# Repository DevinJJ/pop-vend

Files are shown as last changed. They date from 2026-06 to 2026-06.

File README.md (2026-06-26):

# PopVend
PopVend is a 3D-printed mini vending machine that uses a Trigr.dev QR code to accept instant card payments.

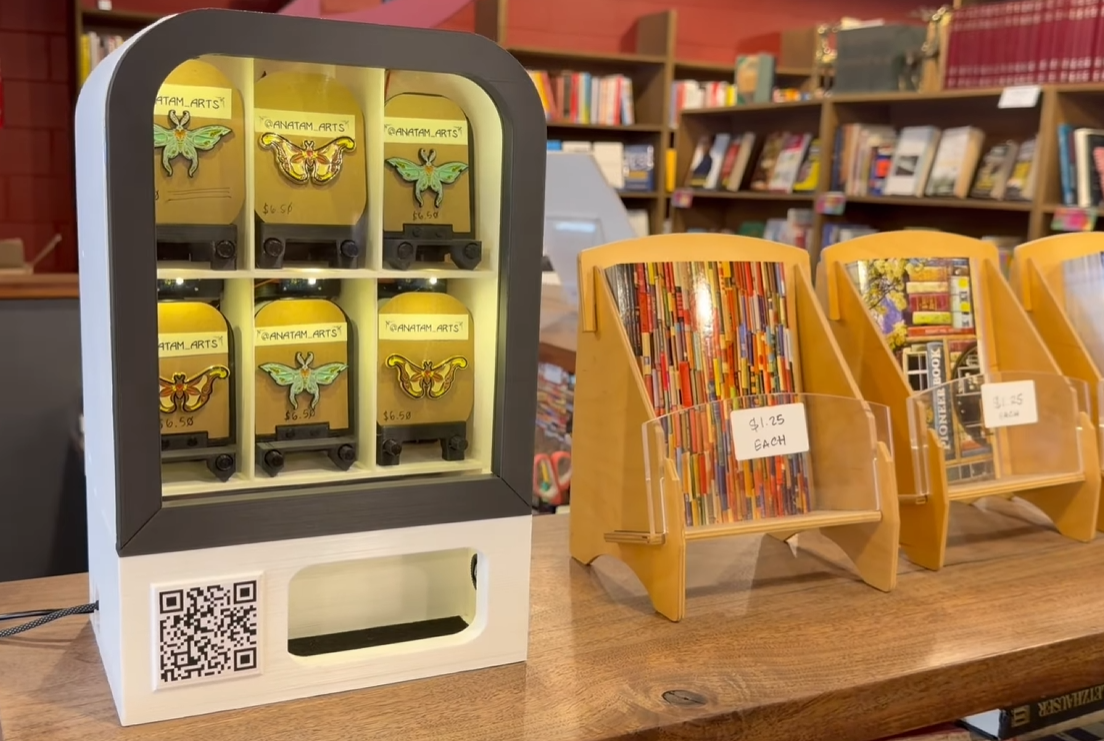
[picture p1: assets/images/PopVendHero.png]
popvend-hero


## Features

* 6 unique item slots that can fit things about the height and length of a credit card
* Fully electronic and automatic vending
* Small front screen with customizable scrolling idle text
* Customizable RGB LEDs above each product
* QR code payments using [Trigr.dev](https://trigr.dev) - Triggers vends instantly after online payments, and payment goes instantly to your own Stripe account  

To print the parts you will need access to a 3D printer that can print up to 250mm high and 142mmx215mm.

**The full build is designed for makers that have some knowledge of electronics, soldering skills and a basic understanding of the Arduino IDE.** As of right now, there are only unsoldered boards available on my [Ko-fi page](https://ko-fi.com/devmode). However, pre-soldered circuit boards and some helpful kits will be available soon that will make the build much much easier. 

## How To Build

Full build tutorial coming soon

## How to use Stripe and Trigr for QR code payments

Once your vending machine is all put together and working, it's time to get it set up to vend automatically with Stripe payments. Luckily, this is made very easy with [Trigr.dev](https://trigr.dev) . 

### Step 1: Make a Trigr account & connect your Stripe account

First, [create an a free account on Trigr](https://trigr.dev/auth/register). Once your account is set up, you will need to follow the instructions to verify your email. Once your email has been verified, you can onboard your Stripe account. To onboard your Stripe account, click the yellow start button at the top of your Trigr dashboard:

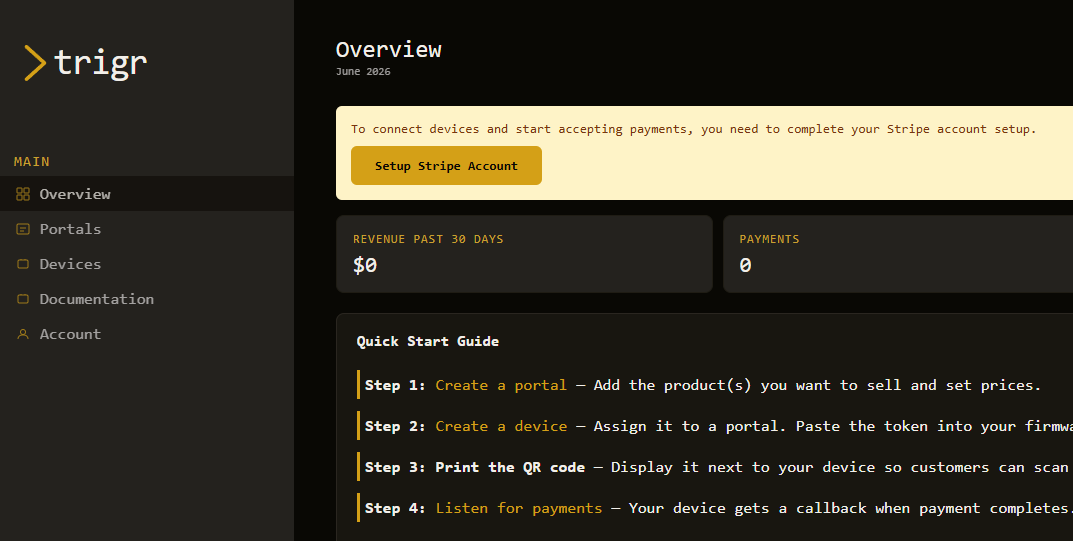
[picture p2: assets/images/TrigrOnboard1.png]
triger-onboarding-dashboard


This will launch the official Stripe onboarding process. If you already have Stripe account that you want to use, that's okay, use that information and it will make onboarding faster.

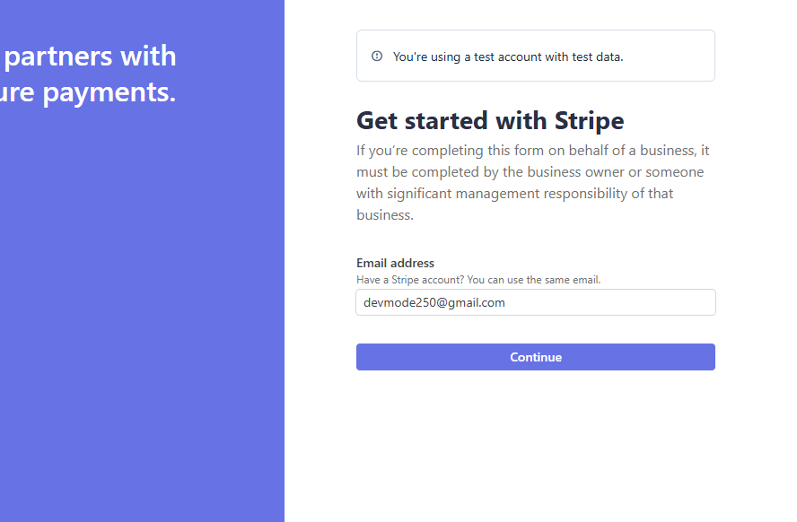
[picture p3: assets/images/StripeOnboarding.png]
stripe-onboarding-first-page


Sometimes it takes a few hours for your info to be processed and approved. You can check your Stripe connection status on your "Account" tab:

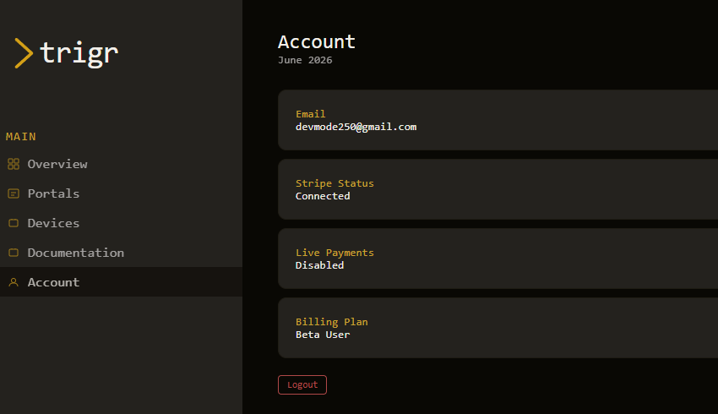
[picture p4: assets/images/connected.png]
trigr-account-tab


### Step 2: Create your Checkout Portal and get your Device token

Next, click on the "Portals" tab in your Trigr dashboard, and click "+ New Portal". This is where you will specify which products you are selling in your vending machine. 

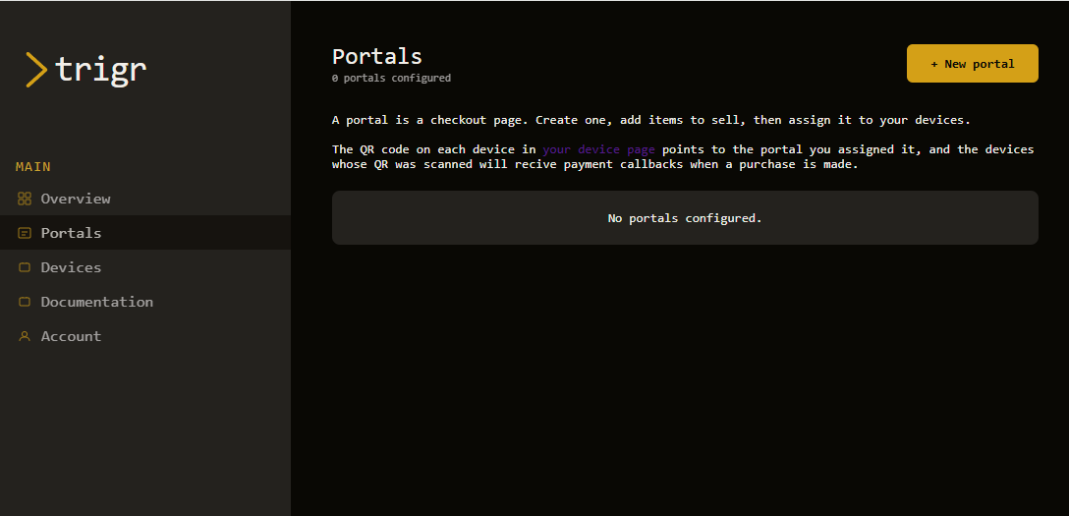
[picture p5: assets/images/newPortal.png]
trigr-portals-tab


Add a product for ALL 6 shelves in the machine, even if they are the same product.

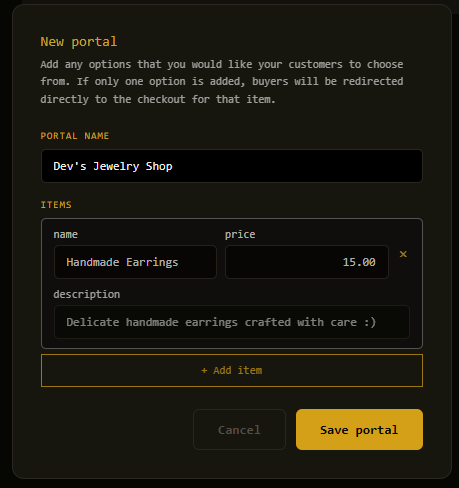
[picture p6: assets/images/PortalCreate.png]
trigr-portal-creation


Once your portal is made, go to the "Devices" tab to create your device. During device creation, use the "portal" dropdown to select the portal you just created.

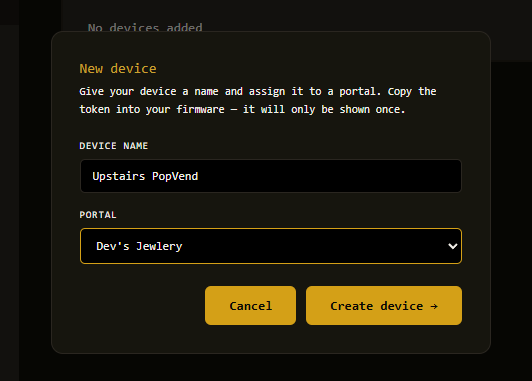
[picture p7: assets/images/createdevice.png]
trigr-device-creation


Once that is done, your Trigr portal is all set up to accept payments from your vending machine. However, keep this page open because you will need it one more time in the final step.

### Step 3: Copy your Trigr tokens into your firmware, and print your QR code

Just a few more things before you're ready to display your machine.

First, you will need to copy some of the tokens that are now available in your Trigr account into your Arduino firmware to flash onto your esp32. Directly at the top of the Arduino firmware provided in '/firmware' are a bunch of configurable parameters to customize your vending machine: 

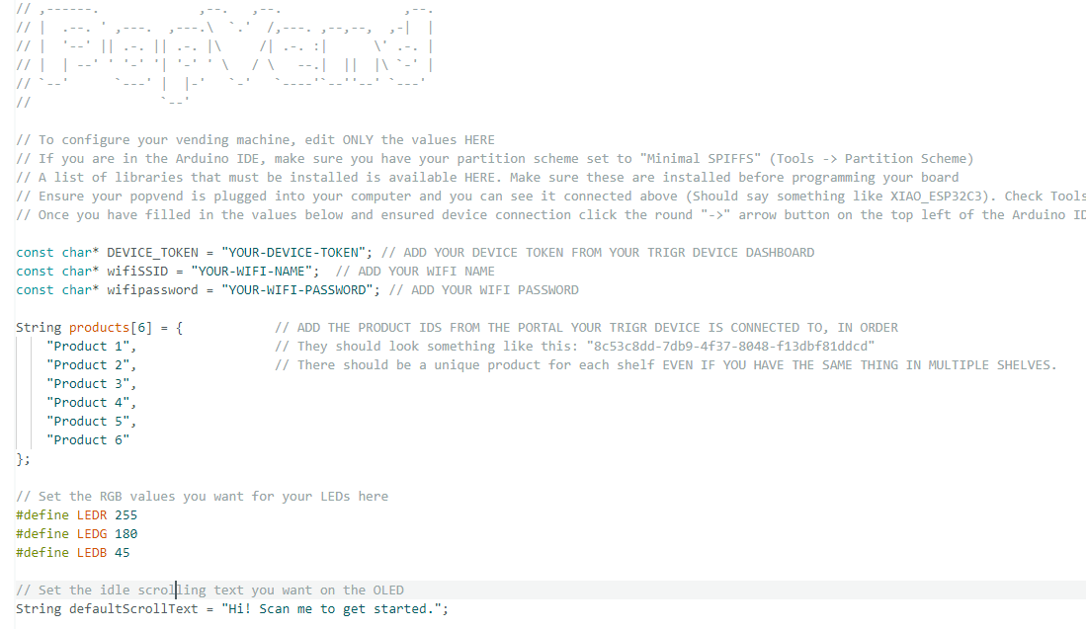
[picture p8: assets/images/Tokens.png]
arduino-ide-firmware-tokens


Here you can customize the LED colors and the scroll text, as well as set up your WiFi credentials and Trigr tokens.

To get your Trigr device token, go back to the "Devices" tab on your Trigr dashboard. Just click on the "Copy Device ID" button and paste it into the Arduino IDE:

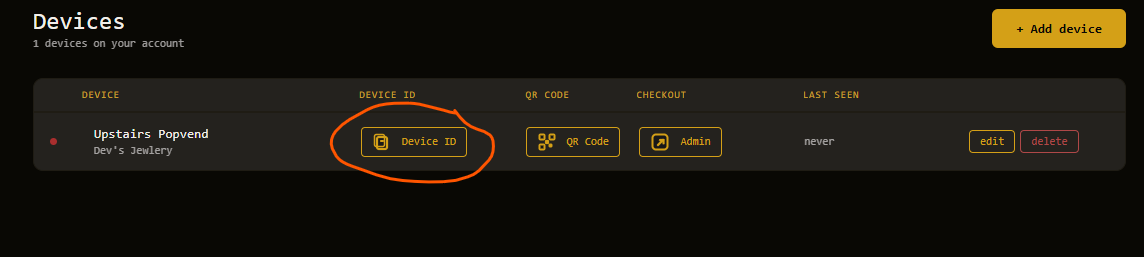
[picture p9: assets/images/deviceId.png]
trigr-copy-device-id


Next, **you will need to add a token for each SHELF in the vending machine (each token should be unique, even if you are selling the same thing on multiple shelves...** just make a separate product for each shelf). To do that, go back to the "Portals" tab and find the portal you set up with your products. There is a "Copy" button displayed next to each product in the portal. There should always be six of these when setting up a PopVend. Copy each one over to the firmware, replacing the text between the quotations marks on lines 19 through 24.

And that's it! Once you re-flash your board with that firmware, you should see the device come online on your Trigr portal. To test your machine, go back to the "Devices" tab and click the "Admin" button on your device. This will take you to a checkout page similar to what a customer will see when they scan your device QR code. Here, you can click on each product and simulate a payment going through by clicking "Trigger Payment Confirmed".

One last thing you'll want to do is go back to the "Devices" tab and click the "QR code" button. This will generate a QR code specifically for your device that you can download to print and mount on your vending machine.

---
*Created by [Devmode](https://www.devinjames.tech/). Need help with your build? Join the [Discord server](https://discord.gg/Y6D79bpH)!

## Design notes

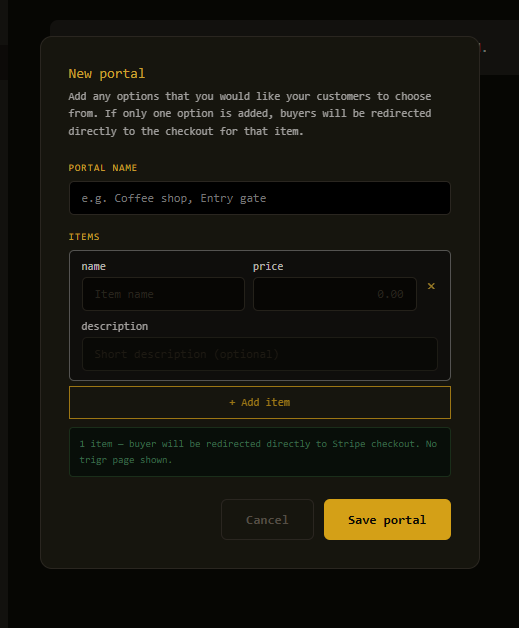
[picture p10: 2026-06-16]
assets/images/createportal.png

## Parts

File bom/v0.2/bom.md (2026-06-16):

# Bill of Materials

Every part required to build a PopVend vending machine is outlined here.

> [NOTE]
> Pricing and availability change frequently.

## Core Electronics

| Item | Qty | Notes | Source |
| --- | --- | --- | --- |
| Servo Motor - FEETECH FS90R | 6 | Continuous Rotation servo to actuate vending | [Amazon](https://www.amazon.com/FEETECH-Continuous-Rotation-Helicopter-Airplane/dp/B097SZQ4CH/ref=sr_1_1_sspa) |
| OLED | 1 |  | [Amazon](https://www.amazon.com/dp/B09MZ8DW4R?ref=ppx_yo2ov_dt_b_fed_asin_title&th=1) |
| BreakBeam Pairs | 3 | | [Adafruit](https://www.adafruit.com/product/2167) |
| Momentary Push Buttons | 6 | Put at the back of each dhelf to detect full retraction | [Amazon](https://www.amazon.com/dp/B07KX24WWS?ref_=ppx_hzsearch_conn_dt_b_fed_asin_title_2&th=1) |
|Neopixel LEDs | 6 | | [Amazon](https://www.amazon.com/dp/B00SK8LY9A?ref=ppx_yo2ov_dt_b_fed_asin_title) |
|XIAO Esp32 C3 | 1 | | [Amazon](https://www.amazon.com/Seeed-Studio-XIAO-ESP32C3-Microcontroller/dp/B0DGX3LSC7/ref=sr_1_1_sspa) |
|Power Chord | 1 | | [Amazon](https://www.amazon.com/dp/B0CKVSS33T?ref_=ppx_hzsearch_conn_dt_b_fed_asin_title_4&th=1) |
|PCBs | 1 | Available UNSOLDERED on my KoFi page... You will need to assemble these yourself. | [KoFi](https://ko-fi.com/s/fa17100ff3) |
|MOSFET Transistor | 1 | Needed for level shifting on the main PCB. | [Amazon](https://www.amazon.com/dp/B08RJ2WKZS?ref=ppx_yo2ov_dt_b_fed_asin_title) |
|10k resistor | 2 | Needed for level shifting on the main PCB. | [Amazon](https://www.amazon.com/EDGELEC-Resistor-Tolerance-Multiple-Resistance/dp/B07QJB31M7/ref=sr_1_1_sspa) |

## Fasteners & Mechanical Hardware

| Item | Qty | Usage | Amazon |
| --- | --- | --- | --- |
| Door Hinges | 2 |  | [Amazon](https://www.amazon.com/dp/B09BHTDFZX?ref_=ppx_hzsearch_conn_dt_b_fed_asin_title_1&th=1) |
| Lock | 1 | | [Amazon](https://www.amazon.com/dp/B0C1P9FT6H?ref_=ppx_hzsearch_conn_dt_b_fed_asin_title_2&th=1) |
| Bearings | 12 | | [Amazon](https://www.amazon.com/dp/B07X2YCNRR?ref_=ppx_hzsearch_conn_dt_b_fed_asin_title_4&th=1) |
| PlexiGlass 8x10 | 1 | For the door frame. If you get the 8x10, you will only need to cut the top corners to fit the frame. | [Amazon](https://www.amazon.com/dp/B0BZS9GQTF?ref_=ppx_hzsearch_conn_dt_b_fed_asin_title_1&th=1) |
|Screws and nuts | ~40 | For securing the shelves, base and back panel. I just used this variety pack | [Amazon](https://www.amazon.com/dp/B0CJ3DKQKS?ref_=ppx_hzsearch_conn_dt_b_fed_asin_title_4&th=1) |

## 3D Printed Parts

Print the parts listed in [stl/v0.2/01-printlist.txt]. STL files are available live under `/stl/v0.2`.

## Consumables & Tools

| Item | Notes | Source |
| --- | --- | --- |
| Leaded solder / Flux | Even if you are getting the pre-assembled PCBs, you will still need to solder the 6 buttons at the back of the shelves. | [Amazon](https://www.amazon.com/s?k=63%2F37+solder+0.8mm) |
| 22 awg Wire | If using the re-assembled PCB, you will only need this for the break beams and the buttons  | [Amazon](https://www.amazon.com/s?k=63%2F37+solder+0.8mm) |
| Wire strippers / cutters |  | [Amazon](https://www.amazon.com/s?k=flush+cutters) |
| JST and Dupont connectors |  | [Amazon](https://www.amazon.com/s?k=flush+cutters) |
| Wire Crimpers | To build wire connectors | [Amazon](https://www.amazon.com/s?k=63%2F37+solder+0.8mm) |
| Small Philips Screwdriver | | [Amazon](https://www.amazon.com/s?k=precision+screwdriver+set) |

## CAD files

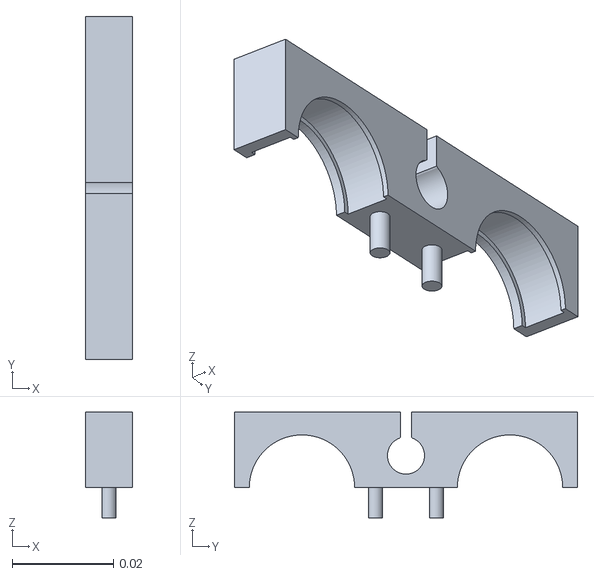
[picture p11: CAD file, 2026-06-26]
stl/v0.2/BearingHousingTop.stl
0.00931 x 0.0676 x 0.0208

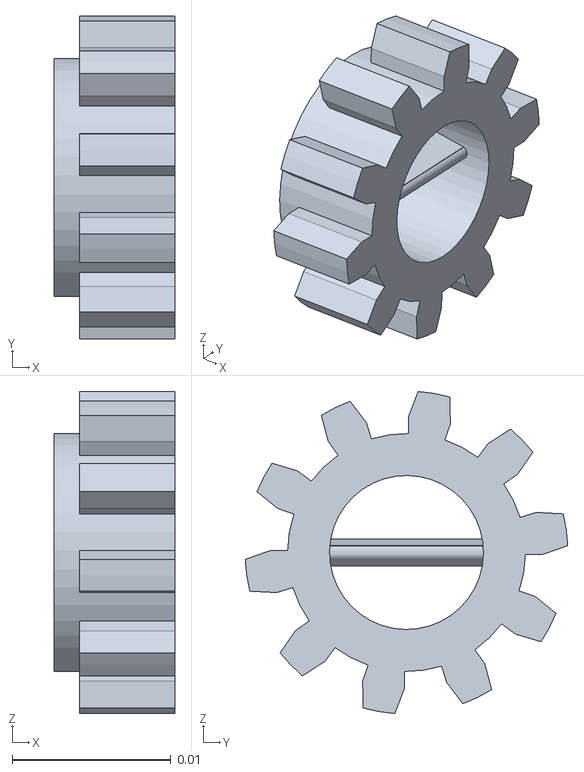
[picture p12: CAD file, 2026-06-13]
stl/v0.2/Gear.stl
0.0076 x 0.0203 x 0.0203

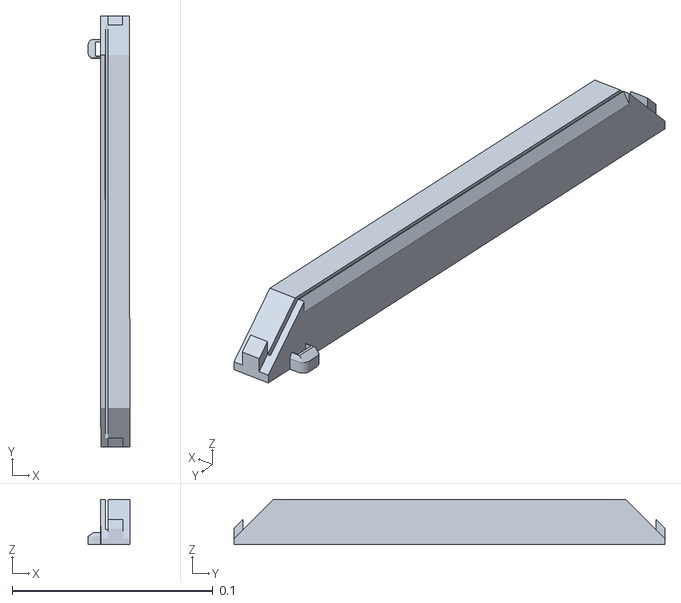
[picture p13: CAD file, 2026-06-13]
stl/v0.2/DoorFrameBottom.stl
0.0208 x 0.215 x 0.0225

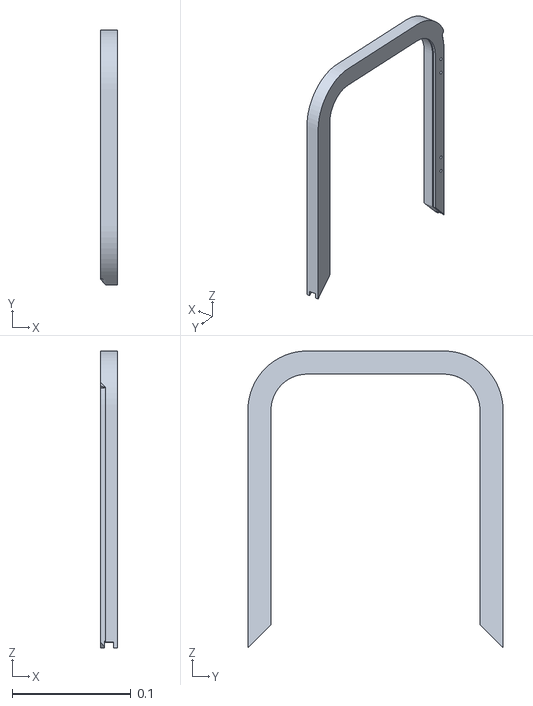
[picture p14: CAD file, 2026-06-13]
stl/v0.2/DoorFrameTop.stl
0.0147 x 0.215 x 0.25

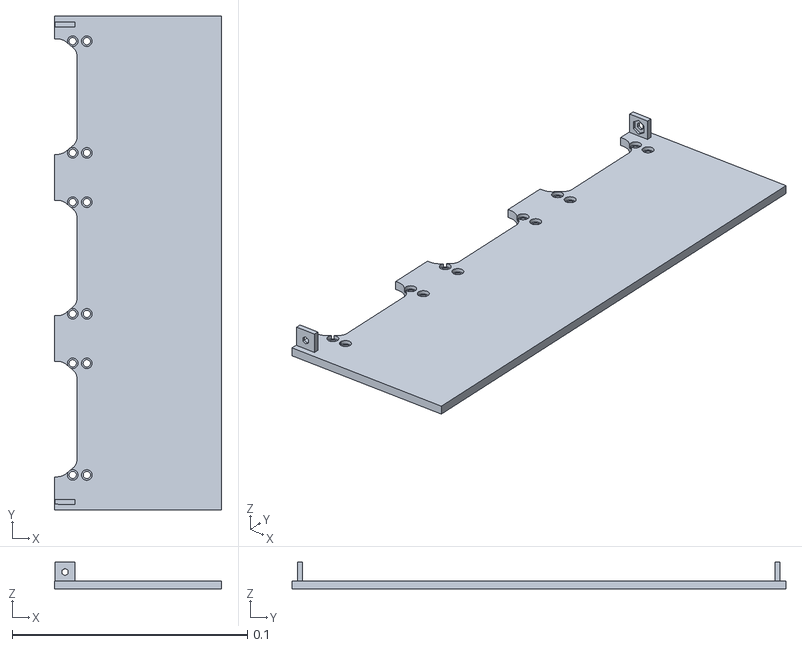
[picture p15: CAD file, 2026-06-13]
stl/v0.2/ShelfBottom.stl
0.0711 x 0.21 x 0.0114

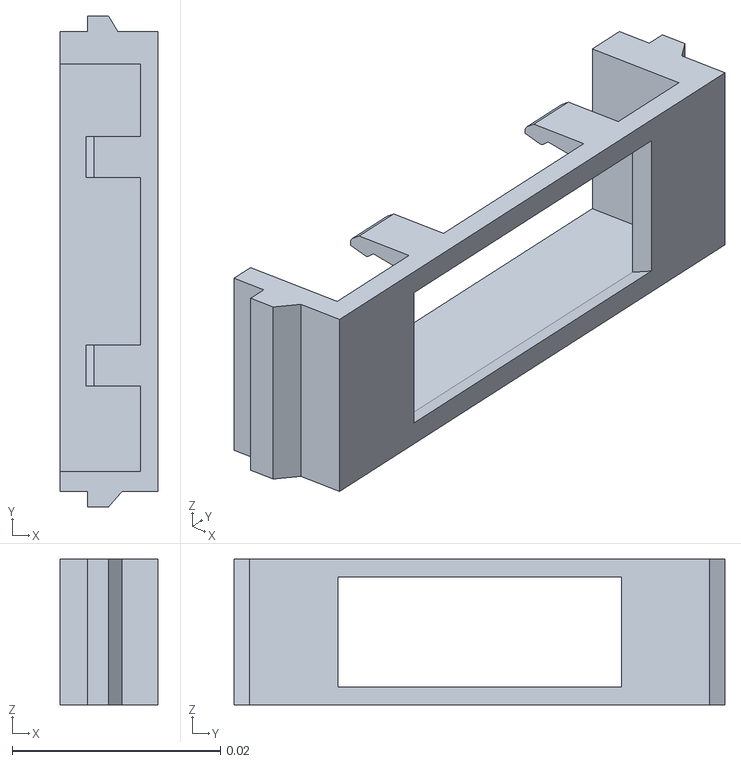
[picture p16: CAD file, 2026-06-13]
stl/v0.2/OledHousing.stl
0.00944 x 0.0471 x 0.014

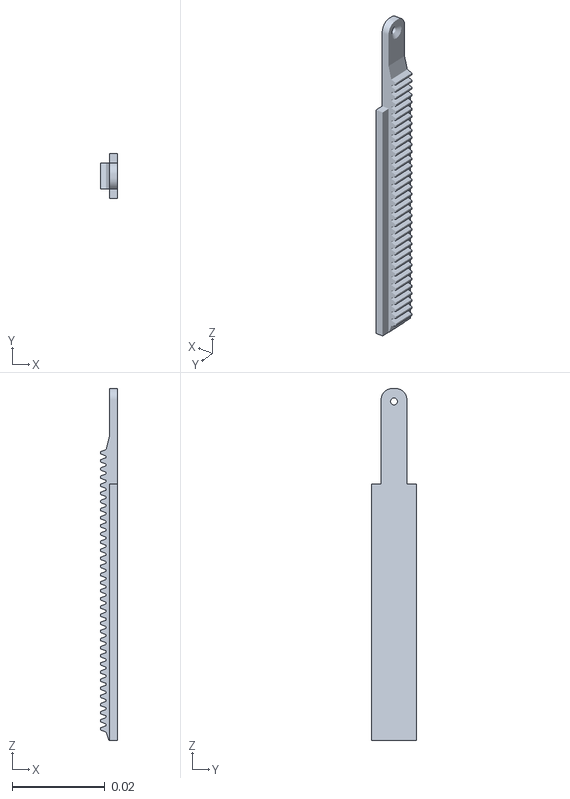
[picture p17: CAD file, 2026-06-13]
stl/v0.2/LockLatch.stl
0.00372 x 0.00976 x 0.0759

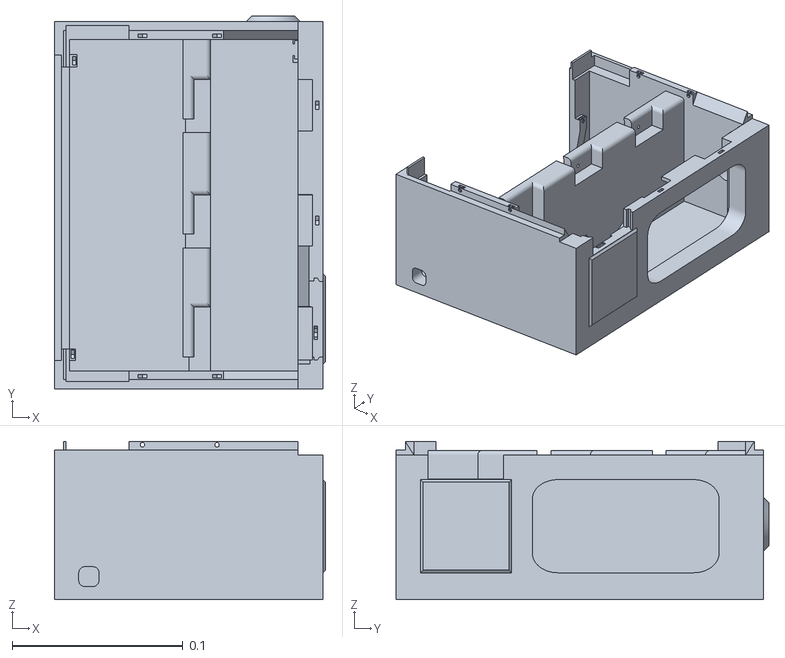
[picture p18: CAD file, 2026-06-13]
stl/v0.2/Base.stl
0.159 x 0.218 x 0.0925

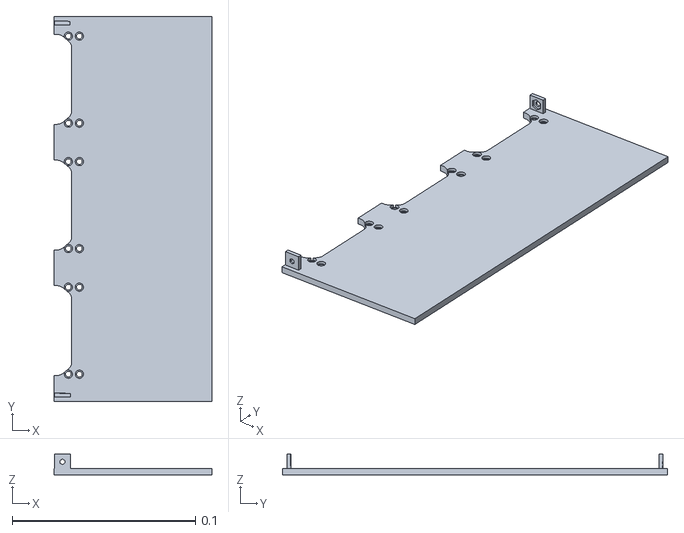
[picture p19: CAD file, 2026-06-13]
stl/v0.2/ShelfTop.stl
0.0861 x 0.21 x 0.0114

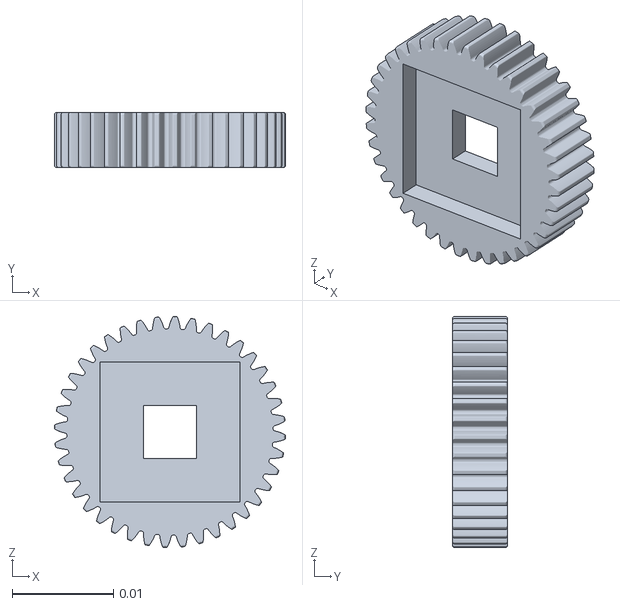
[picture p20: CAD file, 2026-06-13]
stl/v0.2/LockGear.stl
0.0228 x 0.00543 x 0.0228

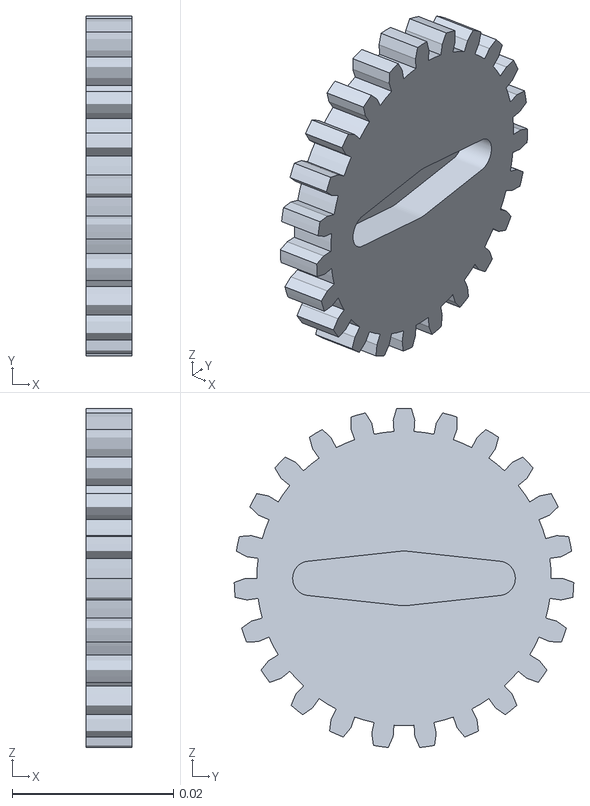
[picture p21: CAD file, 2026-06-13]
stl/v0.2/ServoGear.stl
0.00568 x 0.0421 x 0.042

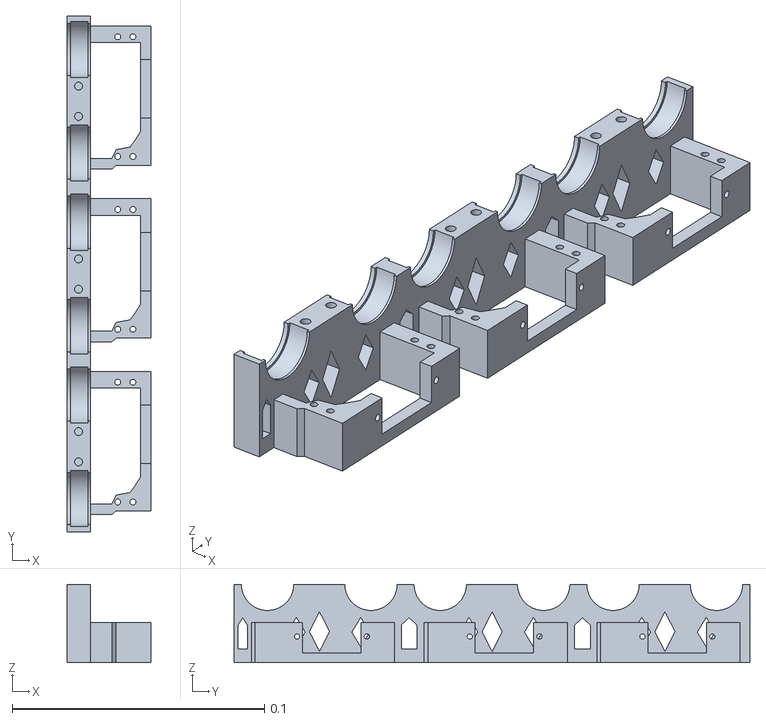
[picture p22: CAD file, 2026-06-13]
stl/v0.2/ServoHousing.stl
0.0335 x 0.205 x 0.0311

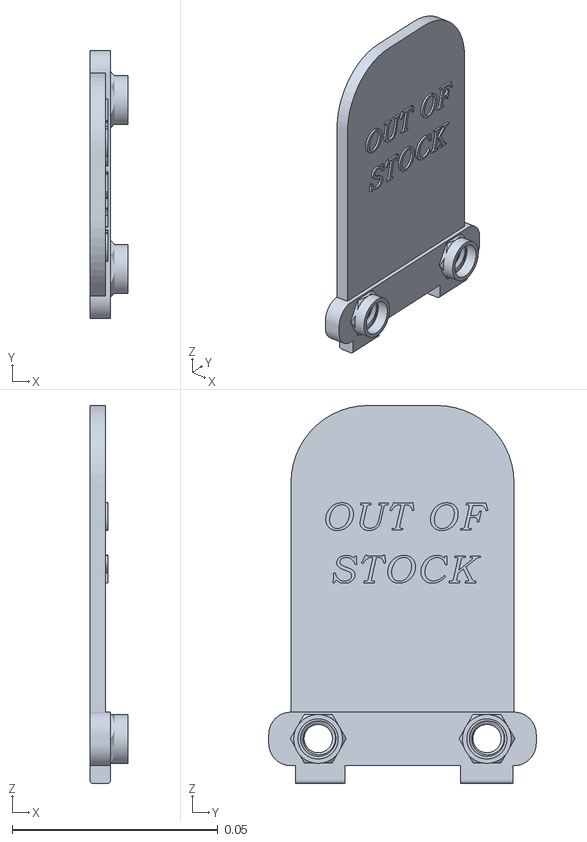
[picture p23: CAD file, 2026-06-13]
stl/v0.2/PushPanel.stl
0.00924 x 0.065 x 0.0918

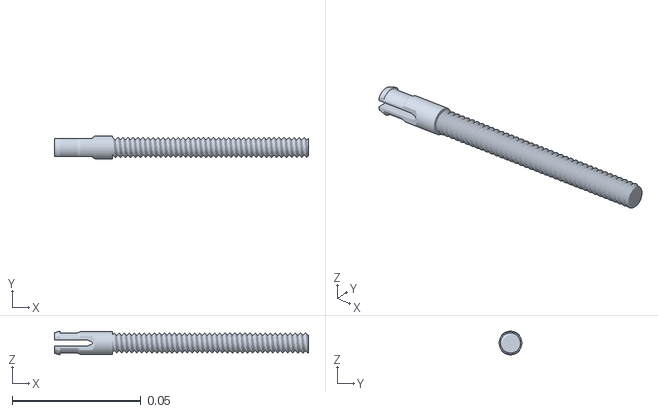
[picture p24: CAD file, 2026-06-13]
stl/v0.2/BoltLong.stl
0.0986 x 0.00881 x 0.0092

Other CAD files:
stl/v0.2/BoltShort.stl

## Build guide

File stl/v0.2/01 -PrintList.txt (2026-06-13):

Base x1
Body x1
DoorFrameTop x1
DoorFrameBottom x1
ServoHousing X2
BearingHousingTop x6
ShelfBottom x1
ShelfTop x1
ServoGear x6
Gear x12
BoltLong x6
BoltShort x6
LockGear x1
LockLatch x1
PushPanel x6
OledHousing x1

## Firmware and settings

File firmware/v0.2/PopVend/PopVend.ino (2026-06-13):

// ,------.             ,--.   ,--.                ,--. 
// |  .--. ' ,---.  ,---.\  `.'  /,---. ,--,--,  ,-|  | 
// |  '--' || .-. || .-. |\     /| .-. :|      \' .-. | 
// |  | --' ' '-' '| '-' ' \   / \   --.|  ||  |\ `-' | 
// `--'      `---' |  |-'   `-'   `----'`--''--' `---'  
//                 `--'                                 

// To configure your vending machine, edit ONLY the values HERE
// If you are in the Arduino IDE, make sure you have your partition scheme set to "Minimal SPIFFS" (Tools -> Partition Scheme)
// A list of libraries that must be installed is available HERE. Make sure these are installed before programming your board
// Ensure your popvend is plugged into your computer and you can see it connected above (Should say something like XIAO_ESP32C3). Check Tools -> Port. There should be some device shown there.
// Once you have filled in the values below and ensured device connection click the round "->" arrow button on the top left of the Arduino IDE

const char* DEVICE_TOKEN = "YOUR DEVICE TOKEN"; // ADD YOUR DEVICE TOKEN FROM YOUR TRIGR DEVICE DASHBOARD
const char* wifiSSID = "YOUR WIFI";  // ADD YOUR WIFI NAME
const char* wifipassword = "YOUR PASSWORD"; // ADD YOUR WIFI PASSWORD

String products[6] = {            // ADD THE PRODUCT IDS FROM THE PORTAL YOUR TRIGR DEVICE IS CONNECTED TO, IN ORDER
    "PRODUCT SHELF 1",            // They should look something like this: "8c53c8dd-7db9-4f37-8048-f13dbf81ddcd"
    "PRODUCT SHELF 2",
    "PRODUCT SHELF 3",
    "PRODUCT SHELF 4",
    "PRODUCT SHELF 5",
    "PRODUCT SHELF 6"
};

// Set the RGB values you want for your LEDs here
#define LEDR 255
#define LEDG 180
#define LEDB 45

// Set the idle scrolling text you want on the OLED
String defaultScrollText = "Hi! Scan me to get started.";

// DO NOT EDIT BELOW THIS POINT UNLESS YOU KNOW WHAT YOU ARE DOING!





















const char* websocket_url = "ws://192.168.1.136:3004";
const char* websocket_url_prod = "wss://trigr.dev";

#include <WiFi.h>
#include <HTTPClient.h>
#include <Update.h>
#include <BLEDevice.h>
#include <BLEServer.h>
#include <BLEUtils.h>
#include <ESPAsyncWebServer.h>
#include <Adafruit_GFX.h>
#include <Adafruit_SSD1306.h>
#include <ArduinoWebsockets.h>
#include <ESP32Servo.h>
#include <EEPROM.h>
#include <Wire.h>
#include <Adafruit_I2CDevice.h>
#include <Adafruit_NeoPixel.h>
#include <ArduinoJson.h>

#define FIRMWARE_VERSION "0.0.3"
#define SCREEN_WIDTH 128
#define SCREEN_HEIGHT 32
#define OLED_ADDR 0x3C
#define EEPROM_SIZE 400
#define CONFIG_SETUP_ADDRESS 0  // Start address for WiFiConfig in EEPROM
#define CONFIG_SSID_ADDRESS 1  // Start address for WiFiConfig in EEPROM
#define CONFIG_PASSWORD_ADDRESS 60   // Start address for WiFiConfig in EEPROM
#define CAT9555_ADDR 0x27
#define PRODUCTION true
#define openingBlinkInterval 50
#define vendTime 1500
#define motorSpeed 70
#define motorSpeedReverse 115
#define NUM_SHELVES 6
#define VEND_TIMEOUT_MS 16000
#define SELECT_TIMEOUT_MS 1000 * 90
#define bounceExtendMs 600

#define SERVICE_UUID        "12345678-1234-1234-1234-1234567890ab"
#define CHARACTERISTIC_UUID "abcdefab-1234-1234-1234-abcdefabcdef"

const int retractionSignalPin = 8;

int lastShelfRetracted = -1;

unsigned long lastPingTime = 0;
const unsigned long pingInterval = 30000;  // Send a ping every 30 sec
unsigned long lastPongTime = 0;
const unsigned long pongTimeout = 50000;   // 90 sec without pong = force reconnect
unsigned long lastRetryTime = 0;
const unsigned long retryTimeout = 10000;   // retry every 10 seconds 

// Arrays to map shelf numbers to light and motor pins
#define LEDSignalPin 2 // GPIO 2
#define BBPin 3 // GPIO 3
const uint8_t motorPins[NUM_SHELVES] = {4,10,5,21,20,9};
Adafruit_NeoPixel pixels(NUM_SHELVES, LEDSignalPin, NEO_GRB + NEO_KHZ800);
bool shelfSelections[NUM_SHELVES] = {false, false, false, false, false, false};

const int NUM_SERVOS = 6;  // Number of servo motors
Servo servos[NUM_SERVOS];   // Array of Servo objects

// Variables to track the blink state for each shelf
unsigned long previousMillis = 0;
bool ledState = false;
const unsigned long selectionBlinkInterval = 500; // 1000 ms for on/off intervals

using namespace websockets;

int currentlyVending = -1;

String pin = "0000";
long pinExpiryTime = 0;

Adafruit_I2CDevice cat9555 = Adafruit_I2CDevice(CAT9555_ADDR, &Wire);
Adafruit_SSD1306 display(SCREEN_WIDTH, SCREEN_HEIGHT, &Wire);

int oledScrollX = 0;
String oledScrollText = "";

Servo m1;
Servo m2;
Servo m3;
Servo m4;
Servo m5;
Servo m6;

struct WiFiConfig {
  char ssid[32];
  char password[64];
  char uid[64];
  char id[64];
  bool setup;
};

WiFiConfig config;
bool restartRequested = false;

enum MachineState {
    STARTING,
    PROVISIONING,
    APACTIVE,
    RECONNECTING,
    CONNECTED,
    VENDING,
    LOADING,
    LOADBOUNCE,
    FAILURE,
    BEAM_OBSTRUCTED,
    WIFICONNECTFAILURE
};

const char* MachineStateNames[] = {
    "STARTING",
    "PROVISIONING",
    "APACTIVE",
    "RECONNECTING",
    "CONNECTED",
    "VENDING",
    "LOADING",
    "LOADBOUNCE",
    "FAILURE",
    "BEAM_OBSTRUCTED",
    "WIFICONNECTFAILURE"
};

// Pre-allocated buffer for messages to websocket
char messageBuffer[300]; // Adjust size based on expected output length

const char ssl_ca_cert[] PROGMEM = \
"-----BEGIN CERTIFICATE-----\n" \
"MIIFazCCA1OgAwIBAgIRAIIQz7DSQONZRGPgu2OCiwAwDQYJKoZIhvcNAQELBQAw\n" \
"TzELMAkGA1UEBhMCVVMxKTAnBgNVBAoTIEludGVybmV0IFNlY3VyaXR5IFJlc2Vh\n" \
"cmNoIEdyb3VwMRUwEwYDVQQDEwxJU1JHIFJvb3QgWDEwHhcNMTUwNjA0MTEwNDM4\n" \
"WhcNMzUwNjA0MTEwNDM4WjBPMQswCQYDVQQGEwJVUzEpMCcGA1UEChMgSW50ZXJu\n" \
"ZXQgU2VjdXJpdHkgUmVzZWFyY2ggR3JvdXAxFTATBgNVBAMTDElTUkcgUm9vdCBY\n" \
"MTCCAiIwDQYJKoZIhvcNAQEBBQADggIPADCCAgoCggIBAK3oJHP0FDfzm54rVygc\n" \
"h77ct984kIxuPOZXoHj3dcKi/vVqbvYATyjb3miGbESTtrFj/RQSa78f0uoxmyF+\n" \
"0TM8ukj13Xnfs7j/EvEhmkvBioZxaUpmZmyPfjxwv60pIgbz5MDmgK7iS4+3mX6U\n" \
"A5/TR5d8mUgjU+g4rk8Kb4Mu0UlXjIB0ttov0DiNewNwIRt18jA8+o+u3dpjq+sW\n" \
"T8KOEUt+zwvo/7V3LvSye0rgTBIlDHCNAymg4VMk7BPZ7hm/ELNKjD+Jo2FR3qyH\n" \ 
"B5T0Y3HsLuJvW5iB4YlcNHlsdu87kGJ55tukmi8mxdAQ4Q7e2RCOFvu396j3x+UC\n" \
"B5iPNgiV5+I3lg02dZ77DnKxHZu8A/lJBdiB3QW0KtZB6awBdpUKD9jf1b0SHzUv\n" \
"KBds0pjBqAlkd25HN7rOrFleaJ1/ctaJxQZBKT5ZPt0m9STJEadao0xAH0ahmbWn\n" \
"OlFuhjuefXKnEgV4We0+UXgVCwOPjdAvBbI+e0ocS3MFEvzG6uBQE3xDk3SzynTn\n" \
"jh8BCNAw1FtxNrQHusEwMFxIt4I7mKZ9YIqioymCzLq9gwQbooMDQaHWBfEbwrbw\n" \
"qHyGO0aoSCqI3Haadr8faqU9GY/rOPNk3sgrDQoo//fb4hVC1CLQJ13hef4Y53CI\n" \
"rU7m2Ys6xt0nUW7/vGT1M0NPAgMBAAGjQjBAMA4GA1UdDwEB/wQEAwIBBjAPBgNV\n" \
"HRMBAf8EBTADAQH/MB0GA1UdDgQWBBR5tFnme7bl5AFzgAiIyBpY9umbbjANBgkq\n" \
"hkiG9w0BAQsFAAOCAgEAVR9YqbyyqFDQDLHYGmkgJykIrGF1XIpu+ILlaS/V9lZL\n" \
"ubhzEFnTIZd+50xx+7LSYK05qAvqFyFWhfFQDlnrzuBZ6brJFe+GnY+EgPbk6ZGQ\n" \
"3BebYhtF8GaV0nxvwuo77x/Py9auJ/GpsMiu/X1+mvoiBOv/2X/qkSsisRcOj/KK\n" \
"NFtY2PwByVS5uCbMiogziUwthDyC3+6WVwW6LLv3xLfHTjuCvjHIInNzktHCgKQ5\n" \
"ORAzI4JMPJ+GslWYHb4phowim57iaztXOoJwTdwJx4nLCgdNbOhdjsnvzqvHu7Ur\n" \
"TkXWStAmzOVyyghqpZXjFaH3pO3JLF+l+/+sKAIuvtd7u+Nxe5AW0wdeRlN8NwdC\n" \
"jNPElpzVmbUq4JUagEiuTDkHzsxHpFKVK7q4+63SM1N95R1NbdWhscdCb+ZAJzVc\n" \
"oyi3B43njTOQ5yOf+1CceWxG1bQVs5ZufpsMljq4Ui0/1lvh+wjChP4kqKOJ2qxq\n" \
"4RgqsahDYVvTH9w7jXbyLeiNdd8XM2w9U/t7y0Ff/9yi0GE44Za4rF2LN9d11TPA\n" \
"mRGunUHBcnWEvgJBQl9nJEiU0Zsnvgc/ubhPgXRR4Xq37Z0j4r7g1SgEEzwxA57d\n" \
"emyPxgcYxn/eR44/KJ4EBs+lVDR3veyJm+kXQ99b21/+jh5Xos1AnX5iItreGCc=\n" \
"-----END CERTIFICATE-----\n";


//const char* websocket_url = "wss://vendstaging.texelpad.com";


int blinkInterval = 2000;
int timeSinceBlinked = 0;
int vendStartTime = 0;
long lastSelectTime = 0;
bool configAPActive = false;
MachineState state = STARTING;  

WebsocketsClient client;
AsyncWebServer server(80);

// HTML form for configuring Wi-Fi credentials
const char* htmlForm = R"rawliteral(
  <!DOCTYPE HTML>
  <html>
  <head>
  </head>
  <body>
    <div class="content">
          <h1>Pop Vend</h1>
          <h3>Wifi Setup</h3>
          <form action="/get" method="get">
            <label>SSID</label>
            <input type="text" name="ssid"><br><br>
            <label>Password</label>
            <input type="password" name="password"><br><br>
            <input class="submit" type="submit" value="Submit">
          </form>
    </div>
  </body>
  <style>
    body { color:white ;font-family: "Verdana"; background-color: #00B5FF; font-size: 2em}
    h1 {font-family: "Brush Script MT"; font-size: 80px}
    .content {width: 95%; margin: auto; align-items: center; max-width: 600px}
    form {display:flex; flex-direction: column;}
    .submit {background-color: #30e000; color: white; font-size: 35px}
    input {height: 60px; border: none;}
    label {margin-bottom:5px; opacity: 0.7}
  </style>
  </html>
)rawliteral";

void setup() {
  Serial.begin(115200);

  config.setup = false;
  WiFi.onEvent(WiFiEvent);

  Wire.begin();

  // Setup OLED  
  display.begin(SSD1306_SWITCHCAPVCC, OLED_ADDR);
  display.clearDisplay();
  display.setTextSize(4);
  display.setTextColor(SSD1306_WHITE);

  setScrollText("Starting up...");


  pixels.begin();

  //runMappingSequenceLights();
  //runMappingSequenceMotors();
  startupLightSequence(4);

  pinMode(BBPin, INPUT_PULLUP);
  

  for (uint8_t i = 0 ; i < NUM_SHELVES ; i++){
    pinMode(motorPins[i], OUTPUT);
    digitalWrite(motorPins[i], LOW);
  }

  pinMode(retractionSignalPin, INPUT_PULLUP);

  // Initialize EEPROM
  if (!EEPROM.begin(EEPROM_SIZE)) {
    //Serial.println("Failed to initialize EEPROM");
    state = FAILURE;
    return;
  }

  //clearWifiConfig();
  loadWifiConfig();

  Serial.println("WiFi configuration:");
  Serial.println(config.ssid);
  Serial.println(config.password);
  Serial.println(config.setup);

  // Start Websocket connection and normal funtionality
  if (config.setup) {
    //Serial.println("WiFi configured");
    connectToWifi(config.ssid, config.password);
  }
  // Start configuration AP
  else {
    Serial.println("WiFi NOT configured");
    startBluetooth();
    setAllLEDs(false);
    //setupAP();
    state = PROVISIONING;
  }

}


unsigned long lastWifiRetryTime = 0;      // Last time we attempted reconnect
const unsigned long retryWifiInterval = 120000; // Retry every 2 minutes if weak signal
const int maxWifiRetries = 0;             // 0 = retry forever, else cap retries
int retryCount = 0;

unsigned long lastLightMove = 0;      // Track light animation timing
int animateLightIndex = 0;                 // Which shelf/light is currently on

unsigned long loadStartTime = 0;       // Track when loading started
const unsigned long loadTimeout = 13000; // Timeout in milliseconds (example: 3 seconds)


int lastStateChecked = -1;
void checkForStateChange(){
  if (state != lastStateChecked){
    //Serial.print("Current state: ");
    //Serial.println(MachineStateNames[state]);
    lastStateChecked = state;
  }

}

void loop() {

  if (restartRequested){
    ESP.restart();
  }

  checkForStateChange();

  for (int i = 0; i < NUM_SHELVES; i++){
    if (shelfSelections[i] && millis() - lastSelectTime >= SELECT_TIMEOUT_MS){
      //sendCommand("TIMEOUT");
      client.send("{\"type\":\"TIMEOUT\",\"device\":\"" + String(DEVICE_TOKEN) + "\"}");
      clearSelection();
    }
  }

  if (oledScrollText.length() > 0){
    scrollTextTick();
  }
  
if (pinExpiryTime > 0 && millis() >= pinExpiryTime) {
    // Expire PIN here
    pin = "0000";
    setScrollText(defaultScrollText);
    pinExpiryTime = 0;  // clear it
}

  if (state == APACTIVE){
    //blinkPin(greenLEDPin);
  }

  else if (state == PROVISIONING){
    // Do something to indicate provisioning status
  }

  else if (state == FAILURE){
    //blinkPin(redLEDPin);
  }

  else if (state == WIFICONNECTFAILURE) {

      // Reconnect is handled by the WiFi library in the Event handler

      if (millis() - lastLightMove > 1000) { // Move every second
          setAllLEDs(false);
          setLED(animateLightIndex, true);

          animateLightIndex++;
          if (animateLightIndex >= NUM_SHELVES) animateLightIndex = 0;

          lastLightMove = millis();
      }

      // ---------------------
      // Check Wi-Fi status
      // ---------------------
      wl_status_t status = WiFi.status();

      // Determine action based on status / reason
      if (status == WL_NO_SSID_AVAIL || status == WL_CONNECT_FAILED) {
          // Invalid credentials - let softAP run in background, do nothing
          // Could optionally log or blink a different pattern
      } 
      else if (status == WL_DISCONNECTED || status == WL_CONNECTION_LOST) {
          // Likely weak signal / temporary drop
          if (millis() - lastWifiRetryTime > retryWifiInterval) {
              // Optional: cap retries if desired
              if (maxWifiRetries == 0 || retryCount < maxWifiRetries) {
                  //Serial.println("Retrying WiFi connection due to weak signal...");
                  WiFi.disconnect();
                  connectToWifi(config.ssid, config.password);
                  lastWifiRetryTime = millis();
                  retryCount++;
              }
          }
      }
      
  }

  else if (state == CONNECTED){
    blinkSelection();
    client.poll();
    //fallDetected();
      // Send a ping every 30 seconds to keep connection alive
      if (millis() - lastPingTime > pingInterval) {
          // Print WIFi signal strength
         // Serial.print("RSSI: ");
          //Serial.println(WiFi.RSSI());
          long rssiValue = WiFi.RSSI();             // get the RSSI
          String rssiStr = String(rssiValue);       // convert to String
          //sendParamCommand("SIG", rssiStr.c_str());  // pass as const char*
          client.ping();
          //Serial.println("Sent ping to server.");
          lastPingTime = millis();
      }

      // Check if we've missed a pong for too long (90 sec)
      if (millis() - lastPongTime > pongTimeout) {
          //Serial.println("No pong received in 90 seconds! Reconnecting WebSocket...");
          client.close();
          state = RECONNECTING;
          lastPongTime = millis();  // Reset timer to prevent immediate reconnect loops
      }

  }

  else if (state == RECONNECTING){
    if (millis() - lastRetryTime > retryTimeout) {
      //Serial.println("Retrying to connect to websocket...");
      connectToSocketServer();
      lastRetryTime = millis();  // Reset timer to prevent immediate reconnect loops
    }
  }

  else if (state == VENDING){
    //digitalWrite(redLEDPin, digitalRead(BBPin));

    if (fallDetected()){
      stopVend();
    }
    else if(millis() - vendStartTime >= VEND_TIMEOUT_MS){
      // Report vend failure
      client.send("{\"type\":\"ERROR\",\"device\":\"" + String(DEVICE_TOKEN) + "\"}");
      stopVend();
    }

  }

  else if (state == LOADING){
    
    if (loadStartTime == 0) {
        loadStartTime = millis();
    }
    
    if (retractionDetected() || (millis() - loadStartTime >= loadTimeout)){
    //Serial.println("Stop Load");
     stopLoad();
     startBounce();
     state = LOADBOUNCE;
     loadStartTime = 0;
    }
  }

  else if (state == LOADBOUNCE){
    if (!retractionDetected()){
      delay(bounceExtendMs);
      //Serial.println("Stop Bounce");
      stopBounce();
        state = CONNECTED;
    }
  }

  else if (state == BEAM_OBSTRUCTED){
    // Blink an LED
    if (!fallDetected()){
      delay(2000);
      state = VENDING;
      startVend();
    }
  }

}

bool retractionDetected(){
  return digitalRead(retractionSignalPin) == LOW;
}

void setLED(uint8_t index, bool on) {

  if (on){
    pixels.setPixelColor(NUM_SHELVES - 1 - index, pixels.Color(LEDR,LEDG,LEDB));
  }
  else{
    pixels.setPixelColor(NUM_SHELVES - 1 - index, pixels.Color(0,0,0));
  }
  pixels.show();

}

void setAllLEDs(bool on) {

  for (int i = 0; i < NUM_SHELVES ; i++ ){
    if (on){
      pixels.setPixelColor(i, pixels.Color(LEDR,LEDG,LEDB));
    }
    else{
      pixels.setPixelColor(i, pixels.Color(0,0,0));
    }
  }

  pixels.show();

}

// void setPin(uint8_t port, uint8_t pin, bool state) {
//   // Calculate the output register address (Port 0 = 0x02, Port 1 = 0x03)
//   uint8_t outputRegister = (port == 0) ? 0x02 : 0x03;

//   // Read the current state of the output register
//   uint8_t buffer[1];
//   cat9555.write_then_read(&outputRegister, 1, buffer, 1);

//   // Update the specific pin state
//   if (state) {
//     buffer[0] |= (1 << pin); // Set the bit for the pin
//   } else {
//     buffer[0] &= ~(1 << pin); // Clear the bit for the pin
//   }

//   // Write the updated value back to the output register
//   uint8_t writeData[2] = {outputRegister, buffer[0]};
//   cat9555.write(writeData, 2);
// }

// void setAllPins(bool state){
//   for (int i = 0; i < 8 ; i++ ){
//     setPin(0, i + 1, state);
//   }
// }

void startupLightSequence(int repetitions){

  setAllLEDs(false);

  for (int i = 0; i < repetitions; i++ ){

    setLED(0, true);
    setLED(2, true);
    setLED(4, true);
    delay(500);
    setAllLEDs(false);
    setLED(1, true);
    setLED(3, true);
    setLED(5, true);
    delay(500);
    setAllLEDs(false);
  }
}

void runMappingSequenceLights(){
  setAllLEDs(false);
  for (int i = 0; i < NUM_SHELVES; i++){
    setLED(i, true);
    delay(3000);
    setLED(i, false);
    delay(3000);
  }
  delay(2000);

  // for (int i = 0; i < NUM_SHELVES){
  //       m1.attach(motorPins[currentlyVending]);
  //       m1.write(motorSpeed);   
  // }

}

void runMappingSequenceMotors(){
  // setAllPins(LOW);
  // for (int i = 0; i < NUM_SHELVES; i++){
  //   shelfSelections[i] = true;
  //   //startVend();
  // }
  // delay(2000);

}

void startBounce(){
        //Serial.println("Start Bounce");
        if (lastShelfRetracted < 0){
          state = CONNECTED;
          return;
        }

        //Serial.println("Bounce shelf ");
        
        currentlyVending = lastShelfRetracted;

       // Serial.println(currentlyVending);

        // Load shelf i
        setAllLEDs(false);               // Turn off all LEDs
        setLED(currentlyVending, true); // Turn on LED for the selected shelf
      
        if (currentlyVending == 0){
          m1.attach(motorPins[currentlyVending]);
          m1.write(motorSpeed);               // Move motor to initial position
        } 
        else if (currentlyVending == 1){
          m2.attach(motorPins[currentlyVending]);
          m2.write(motorSpeed);               // Move motor to initial position
        }
        else if (currentlyVending == 2){
          m3.attach(motorPins[currentlyVending]);
          m3.write(motorSpeed);               // Move motor to initial position
        }
        else if (currentlyVending == 3){
          m4.attach(motorPins[currentlyVending]);
          m4.write(motorSpeed);               // Move motor to initial position
        }
        else if (currentlyVending == 4){
          m5.attach(motorPins[currentlyVending]);
          m5.write(motorSpeed);               // Move motor to initial position
        }
        else if (currentlyVending == 5){
          m6.attach(motorPins[currentlyVending]);
          m6.write(motorSpeed);               // Move motor to initial position
        }
}

void startLoad(){
        //Serial.println("Start Load");
        // Check if done vending
        if (getNextVendIndex() < 0) {
          state = CONNECTED;
          return;
        };
        
        // Check if button pressed
        if (retractionDetected()){
          state = CONNECTED;
          return;
        }

        currentlyVending = getNextVendIndex();

        //Serial.println("Currentlyvending: ");
        //Serial.println(currentlyVending);

        lastShelfRetracted = currentlyVending;

        if (currentlyVending >= 0 && currentlyVending < NUM_SHELVES && shelfSelections[currentlyVending]) { // Ensure bounds and check selection
            // Load shelf i
            setAllLEDs(false);               // Turn off all LEDs
            setLED(currentlyVending, true); // Turn on LED for the selected shelf
          
            if (currentlyVending == 0){
              m1.attach(motorPins[currentlyVending]);
              m1.write(motorSpeedReverse);               // Move motor to initial position
            } 
            else if (currentlyVending == 1){
              m2.attach(motorPins[currentlyVending]);
              m2.write(motorSpeedReverse);               // Move motor to initial position
            }
            else if (currentlyVending == 2){
              m3.attach(motorPins[currentlyVending]);
              m3.write(motorSpeedReverse);               // Move motor to initial position
            }
            else if (currentlyVending == 3){
              m4.attach(motorPins[currentlyVending]);
              m4.write(motorSpeedReverse);               // Move motor to initial position
            }
            else if (currentlyVending == 4){
              m5.attach(motorPins[currentlyVending]);
              m5.write(motorSpeedReverse);               // Move motor to initial position
            }
            else if (currentlyVending == 5){
              m6.attach(motorPins[currentlyVending]);
              m6.write(motorSpeedReverse);               // Move motor to initial position
            }
        }
}
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

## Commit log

2026-06-15 Update BOM
2026-06-26 update bearingHousingTop STL
    [BearingHousingTop.stl]
